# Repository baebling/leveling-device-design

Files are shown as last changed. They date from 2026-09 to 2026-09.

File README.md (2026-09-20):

# 수평유지 상부모듈 — 수동 턴버클 Rev M2 우선

> **2026-09-08 현행 범위:** [상부 패널 없는 공개형 프로파일 시연](requirements/current_open_frame_demo_scope_2026-09-08.md). 카트·적재물·사람, 별도 과조절 스토퍼/전용 받침, 전용 시험대 고정품은 구매하지 않는다. 남은 구매 전 작업은 활성20행 재검산과 최종 견적이다.

> **진행상황 기록:** [2026-09-07 M2R2-S220 현재 상태](logs/current_progress_2026-09-07.md)

> **현행 실행 우선순위:** [2026-09-07 수동 M2R2-S220 1순위 및 구매 전 게이트](requirements/current_variant_priority_2026-09-07.md). 전동 Rev E는 향후 참고안이며 현재 주문 기준이 아니다.

> **현행 시연 범위:** 카트·적재물 없는 자중 전용 감독하 시연. [구매 전 점검 결과와 열린 항목](verification/m2r2s220_no_cart_pre_purchase_audit_2026-09-07.md)

> **이전 한 축 상세 M2R2F2는 조립 방법 참고용 이력이다.** [3D 조립/분해 STEP과 렌더](outputs/manual_m2r2f2_one_axis/README.md), [확인 치수와 남은 가정](design_basis/manual_m2r2f2_one_axis_assembly_2026-09-05.md). 해당 모델의 MCL-12-F 칼라는 현행 M2R2-S220에서 SCSJ12-6으로 대체됐다.

> **현재 최신은 개념 승인 후 만든 M2R2-S220 장바구니 부품 CAD다.** [CAD 패키지 설명](outputs/manual_turnbuckle_rev_m2r2s220/README.md), [설계·자유도 검토](design_basis/manual_m2r2_cart_dof_assessment_2026-09-06.md). 하부 관절만 기존 4080 슬롯 안쪽으로 옮겨 중립 높이299.2 mm와 ±3° 길이 여유5.42 mm를 확보했다. 부품 간섭과 M5/M8 공구축 및 STEP 재읽기는 통과했지만, 독립 기계식 스톱·실제 카트 래치·STB 압축 정격 때문에 구매/제작 릴리스는 아직 아니다.

> **최신 검토 CAD는 M2R2 기성 연결부형이다.** 후속 요청에 따라 프로파일 길이 절단만 허용하고 맞춤 평판·부시·추가 구멍 가공을 없애는 조립안으로 변경했다. [최신 CAD 안내](outputs/manual_turnbuckle_rev_m2r2/README.md), [부품 후보·절단표·조립 순서](design_basis/manual_revm2r2_stock_connections_2026-09-05.md). 앞1/뒤2 직교 3-RPS, 검토 외곽700×700×344 mm. 아래 M2R1 및 120° 유지 방침은 이전 이력이다. 구매·제작·실물 하중 검증은 완료되지 않았다.

> **현재 CAD: Rev M2R1 (2026-09-05).** 사용자 CAD 진행 요청에 따라 기존 Rev M2 상부 연결부를 수정했다. [CAD 패키지 안내](outputs/manual_turnbuckle_rev_m2r1/README.md), [중립 STEP](outputs/manual_turnbuckle_rev_m2r1/step/M2R1_NEUTRAL_REVIEW.step), [전체 ZIP](output/Manual_3RPS_RevM2R1_CAD_Review_2026-09-05.zip). 112개 구성요소, 9자세 부품 간 간섭 0건, 5개 STEP 재수입 통과. 부시/구면 형상/핀 적층은 공칭 가정이며 제작·구매 미승인이다.

- **외관·조립 개선:** [표준 표면과 축 표시, 동일 링크 키트 3개](design_basis/manual_revm2_appearance_assembly_2026-09-05.md). 형상 재설계 대신 조립 표준화와 구조 가시성을 개선하는 개념이며 제작 승인 전이다.

> **2026-09-05 최종 사용자 결정:** 설명력과 기존 검증자료 활용을 고려해 턴버클형 Rev M2를 다시 1순위로 정했다. 경첩형 M3는 비교안으로 보관한다. 구조를 새로 단순화하기보다 좌나사품·상부 부시/핀·압축 사용 확인과 조달 묶음에 집중한다. 아래 같은 날짜의 M3 우선 결정은 대체된 이력이다.

- [최신 우선순위](requirements/current_turnbuckle_priority_2026-09-05.md)
- [최소 완성 방안 및 기존 검증 재감사](design_basis/manual_revm2_minimal_completion_2026-09-05.md)
- [조달 묶음](procurement/manual_revm2_procurement_groups_2026-09-05.md) / [공급처·담당자 문의 초안](procurement/manual_revm2_supplier_inquiry_drafts_2026-09-05.md)
- 기존 상부 부시의 실제 형상/공차는 검증되지 않았다. 구매·제작 미승인, 문의 미발송.

## 아래는 같은 날 앞서 검토한 M3 이력

> **2026-09-05 최신 결정:** 빠른 마무리·낮은 작업부담·재료 중심 조달을 위해 기계식을 1순위로 변경했다. 기존 구조를 유지할 의무는 없다. 새 우선 개념은 직교 경첩 2축과 조절나사 2개의 수동 수평조절·고정 구조다. 독립 상승/자동보정은 이번 실행 가정에서 제외한다. Rev E와 Rev M2는 보관안이며 아래의 이전 우선순위/BOM은 현재 주문 기준이 아니다.

- 최신 범위: [수동 우선순위](requirements/current_manual_priority_2026-09-05.md)
- 새 구조·예비계산·미해결사항: [M3 개념설계](concepts/manual_crossed_hinge_m3_2026-09-05.md)
- 상판 중심은 기울기에 따라 종속 이동한다. 절대 X/Y 고정이 필수이면 이 개념을 다시 검토한다.
- 현재 개념검토 단계이며 상세 CAD·구매·제작·실물검증은 미완료/미승인이다. 비용분류 및 축소 성과 인정도 확인 전이다.

## 아래는 2026-09-04 이전 전동식/수동식 작업 이력

> **2026-09-04 최신 상태:** Rev E의 제작도·전장함 배치·회로/배선·Mega2560 펌웨어·후보 BOM·시험절차를 release candidate로 구현했다. 27자세 OpenCascade 3회, 기존 Fusion 간섭 3회/단면 3회, Mega2560 실제 컴파일, 전체 226개 회귀시험과 RC1 전용시험 10개가 통과했다. 공급자/실물 검증이 남아 구매·제작·통전 승인은 아직 false다.

최신 자료:

- 실행 기준: [`requirements/current_variant_priority_2026-09-04.md`](requirements/current_variant_priority_2026-09-04.md)
- 디지털 감사: [`verification/RevE_PoC_release_candidate_audit_2026-09-04.md`](verification/RevE_PoC_release_candidate_audit_2026-09-04.md)
- 제작자료: [`fabrication/profile_radial_revE_release_candidate_2026-09-04`](fabrication/profile_radial_revE_release_candidate_2026-09-04)
- 전장·공급자·후보 BOM: [`outputs/profile_radial_revE_poc_release_candidate`](outputs/profile_radial_revE_poc_release_candidate)
- 타 PC 전달 ZIP: [`output/Profile_Radial_3RPS_RevE_PoC_RC1_2026-09-04.zip`](output/Profile_Radial_3RPS_RevE_PoC_RC1_2026-09-04.zip)
- 펌웨어: [`firmware/reve_leveling_controller`](firmware/reve_leveling_controller)
- 시험절차: [`verification/RevE_PoC_test_protocol_2026-09-04.md`](verification/RevE_PoC_test_protocol_2026-09-04.md)
- 수행 및 시행착오: [`logs/reve_poc_implementation_2026-09-04.md`](logs/reve_poc_implementation_2026-09-04.md)

> **2026-09-02 최신 상태:** `LM4075OE-1075 x3 + MDD10A x2 + Mega2560 + MPU6050` 전동 자동수평 Rev E의 CAD 단계를 완료했다. 실제 액추에이터 STEP를 넣은 Fusion 단일 조립체, 27자세 해석, OpenCascade 검사와 Fusion 간섭검사 3회가 통과했다. 수동 턴버클 Rev M2는 우선순위 2 백업안이며 두 안 모두 주문·제작 승인은 아직 false다.

```text
PRIORITY_1 = POWERED_PROFILE_RADIAL_3RPS_REVE_ACTUAL_VENDOR
PRIORITY_2 = MANUAL_TURNBUCKLE_3RPS_REV_M2_BACKUP
TARGET_POWERED_Z = 0-50 mm
TARGET_PITCH_ROLL = +/-3 deg
CAD_STAGE = COMPLETE
PURCHASE_RELEASE = FALSE
FABRICATION_RELEASE = FALSE
COMMISSIONING_RELEASE = FALSE
```

우선순위 1에서 먼저 읽을 파일:

- 최신 우선순위: [`requirements/current_variant_priority_2026-09-02.md`](requirements/current_variant_priority_2026-09-02.md)
- 전동 제어 기준: [`design_basis/priority1_powered_control_architecture_2026-09-02.md`](design_basis/priority1_powered_control_architecture_2026-09-02.md)
- Rev E CAD·반복검증: [`design_basis/Profile_Radial_3RPS_RevE_CAD_validation_2026-09-02.md`](design_basis/Profile_Radial_3RPS_RevE_CAD_validation_2026-09-02.md)
- 60행 국내 구매형 BOM: [`procurement/profile_radial_reve_domestic_master_bom_2026-09-02.csv`](procurement/profile_radial_reve_domestic_master_bom_2026-09-02.csv), [`설명서`](procurement/profile_radial_reve_domestic_master_bom_2026-09-02.md)
- 검토용 Excel BOM: [`outputs/profile_radial_revE_actual_vendor/Profile_Radial_3RPS_RevE_Domestic_BOM_2026-09-02.xlsx`](outputs/profile_radial_revE_actual_vendor/Profile_Radial_3RPS_RevE_Domestic_BOM_2026-09-02.xlsx)
- Fusion 단일 조립체: [`outputs/profile_radial_revE_actual_vendor/Profile_Radial_3RPS_RevE_ACTUAL_VENDOR.f3d`](outputs/profile_radial_revE_actual_vendor/Profile_Radial_3RPS_RevE_ACTUAL_VENDOR.f3d)
- STEP·렌더·검증 패키지: [`outputs/profile_radial_revE_actual_vendor`](outputs/profile_radial_revE_actual_vendor)
- 국내 제어부 조사: [`web_research/domestic_electronics_research_log_2026-09-02.md`](web_research/domestic_electronics_research_log_2026-09-02.md)
- 타 PC 전달 패키지: [`output/Profile_Radial_3RPS_RevE_CAD_Package_2026-09-02.zip`](output/Profile_Radial_3RPS_RevE_CAD_Package_2026-09-02.zip), [`SHA-256`](output/Profile_Radial_3RPS_RevE_CAD_Package_2026-09-02.zip.sha256)

우선순위 2 수동 백업안:

- 설계 기준: [`design_basis/manual_turnbuckle_rev_m2_2026-09-02.md`](design_basis/manual_turnbuckle_rev_m2_2026-09-02.md)
- BOM: [`procurement/manual_turnbuckle_rev_m2_bom_2026-09-02.md`](procurement/manual_turnbuckle_rev_m2_bom_2026-09-02.md)
- CAD/검증 결과: [`outputs/manual_turnbuckle_rev_m2`](outputs/manual_turnbuckle_rev_m2)
- 자립성 감사: [`outputs/manual_turnbuckle_rev_m2/Manual_3RPS_RevM2_self_standing_verification.json`](outputs/manual_turnbuckle_rev_m2/Manual_3RPS_RevM2_self_standing_verification.json)
- 최신 타 PC 전달 패키지: [`output/Manual_3RPS_RevM2_CadQuery_Package_v2_2026-09-02.zip`](output/Manual_3RPS_RevM2_CadQuery_Package_v2_2026-09-02.zip)
- 재생성: `powershell -ExecutionPolicy Bypass -File scripts/run_manual_turnbuckle_rev_m2.ps1`

> **2026-09-01 과거 결정:** 전동 액추에이터·IMU·모터제어·전원장치를 제외하고 수동식으로 전환했으나, 이 결정은 2026-09-02의 우선순위 변경으로 대체됐다. 아래 내용은 수동 백업안의 이력이다.

현재 상태:

```text
BACKUP_VARIANT = MANUAL_ADJUSTABLE_3RPS_HISTORY
POWERED_VARIANT = PRIORITY_1_REACTIVATED
TARGET_MANUAL_Z = 0-50 mm provisional
TARGET_PITCH_ROLL = +/-3 deg
PURCHASE_RELEASE = FALSE
FABRICATION_RELEASE = FALSE
```

현재 먼저 읽을 파일:

- 수동 요구사항: [`requirements/current_manual_scope_2026-09-01.md`](requirements/current_manual_scope_2026-09-01.md)
- 수동 설계 기준: [`design_basis/manual_adjustable_3rps_baseline_2026-09-01.md`](design_basis/manual_adjustable_3rps_baseline_2026-09-01.md)
- 전동안 보관 기록: [`design_basis/archived_powered_control_architecture_2026-09-01.md`](design_basis/archived_powered_control_architecture_2026-09-01.md)
- BOM 변경표: [`procurement/manual_3rps_bom_delta_2026-09-01.csv`](procurement/manual_3rps_bom_delta_2026-09-01.csv)
- 인수인계: [`PROJECT_HANDOFF.md`](PROJECT_HANDOFF.md)

수동안은 기존 Rev D의 700 x 700 mm 프로파일 프레임, 250 mm 지지 반경과 90/210/330 deg 지지점은 재사용 후보로 유지한다. 27자세 이상모델의 요구 핀 중심 길이는 212.137-297.864 mm이며, 새 수동 지지대의 예비 설계 포락체는 205-305 mm다. 정확한 스크루·너트·조인트·잠금장치를 선정하고 Fusion 조립체를 다시 검사하기 전에는 주문하거나 제작하지 않는다.

## 보관된 전동안 - 프로파일 방사형 3-RPS Rev D

> **보관 시점 최종 갱신:** Rev D 기술 BOM을 62개 고유 행으로 평탄화했다. 가격 확인분은 VAT 포함 화면가 1,589,208원이고, 이 중 나비엠알오 45행 소계는 1,085,370원이다. 별도 견적이 필요한 A6061 가공품은 9행이며 Fusion 조립체는 루트 전체 간섭 0건과 회귀검사 18개를 유지한다.

> **전동안 보관 판정:** 아래 기술 BOM은 현재 `ARCHIVED_DO_NOT_ORDER`다. 당시에도 액추에이터 정확 옵션/배선자료, LMB-10 핀 포함품, 가공 견적과 최종 결제총액이 닫히지 않아 `purchase_release=false`, `fabrication_release=false`였다.

전동안 보관 파일:

- Fusion 원본: [`outputs/profile_radial_revD_fusion_native/Profile_Radial_3RPS_RevD_NATIVE.f3d`](outputs/profile_radial_revD_fusion_native/Profile_Radial_3RPS_RevD_NATIVE.f3d)
- 최종 통합 BOM: [`outputs/bom/Profile_Radial_3RPS_RevD_Final_BOM_2026-09-01.xlsx`](outputs/bom/Profile_Radial_3RPS_RevD_Final_BOM_2026-09-01.xlsx), [`CSV`](procurement/profile_radial_revd_final_master_bom_2026-09-01.csv), [`설명서`](procurement/profile_radial_revd_final_master_bom_2026-09-01.md)
- Rev D 설계·조립 기준: [`design_basis/profile_radial_revD_fusion_native_2026-08-31.md`](design_basis/profile_radial_revD_fusion_native_2026-08-31.md)
- Rev D 구조·체결 BOM: [`procurement/profile_radial_revD_structural_bom_2026-08-31.md`](procurement/profile_radial_revD_structural_bom_2026-08-31.md)
- Rev D 최신 분할 구매안: [`procurement/profile_radial_revd_split_source_purchase_plan_2026-09-01.md`](procurement/profile_radial_revd_split_source_purchase_plan_2026-09-01.md), [`주문 그룹 CSV`](procurement/profile_radial_revd_split_source_order_groups_2026-09-01.csv)
- Rev D 발주표 재감사: [`procurement/profile_radial_revd_order_readiness_audit_2026-09-01.md`](procurement/profile_radial_revd_order_readiness_audit_2026-09-01.md)
- Rev D 나비엠알오 실상품 후보 BOM: [`procurement/profile_radial_revd_navimro_candidate_bom_2026-09-01.md`](procurement/profile_radial_revd_navimro_candidate_bom_2026-09-01.md), [`CSV`](procurement/profile_radial_revd_navimro_candidate_bom_2026-09-01.csv)
- 과거 일괄 발주 준비도: [`procurement/profile_radial_revd_single_order_readiness_2026-09-01.md`](procurement/profile_radial_revd_single_order_readiness_2026-09-01.md)
- ISO 검토 이미지: [`outputs/profile_radial_revD_fusion_native/Profile_Radial_3RPS_RevD_Fusion.png`](outputs/profile_radial_revD_fusion_native/Profile_Radial_3RPS_RevD_Fusion.png)
- 가공 DXF/좌표표: [`outputs/profile_radial_revD_fusion_native/fabrication`](outputs/profile_radial_revD_fusion_native/fabrication)
- 기존 Rev C와 그 이전 자료는 비교·시행착오 기록이며 현재 주문 기준이 아니다.

> **2026-08-31 이전 상태(Rev C):** Rev B 기각 후 실제 120 deg 방사형 3-RPS를 복구했던 단계다. 수동 전환 직전 전동안에서는 이 구조의 중앙 허브판까지 제거한 Rev D가 마지막 기준이었다.

이 저장소는 기존 자재운반 카트와 하부 이동체 사이에 설치하는 독립형 수평유지·리프팅 상부모듈 및 기계식 카트 결합 인터페이스의 PoC 개념설계 자료이다.

## 2026-09-01 보관된 전동안의 마지막 방향

수동 전환 직전까지 과거 중앙 카단, 잘못 조립된 Rev B, 중앙 허브판을 사용한 Rev C는 **역사/비교 자료**로 보관했고, 전동안의 마지막 기준은 허브판 없는 프로파일 방사형 Rev D였다.

- 목표 구조: 하부 회전힌지(R) + 엔코더 액추에이터(P) + 상부 구면 로드엔드(S) × 3
- 허용 자유도: Z, pitch, roll
- 기구 구속: 세 하부 R축 평면 구속으로 X, Y, yaw가 종속되며, 27자세 해석에서 최대 보정량은 X 0.342 mm, Y 0.171 mm, yaw 0.079 deg다.
- 현재 Fusion 360 검토 패키지: [`output/Profile_Radial_3RPS_RevD_Fusion360_Native.zip`](output/Profile_Radial_3RPS_RevD_Fusion360_Native.zip)
- Rev D 설계 기준: [`design_basis/profile_radial_revD_fusion_native_2026-08-31.md`](design_basis/profile_radial_revD_fusion_native_2026-08-31.md)
- Rev D 구조 BOM: [`procurement/profile_radial_revD_structural_bom_2026-08-31.md`](procurement/profile_radial_revD_structural_bom_2026-08-31.md)
- 로컬 어댑터·스톱 가공자료: [`outputs/profile_radial_revD_fusion_native/fabrication`](outputs/profile_radial_revD_fusion_native/fabrication)
- Rev B 기각 재감사: [`design_basis/revB_assembly_reaudit_2026-08-31.md`](design_basis/revB_assembly_reaudit_2026-08-31.md)
- 유지 검토 후보: LM4075OE-1075 24 V/100 mm/5 V encoder, DMD-150 ×3, Arduino Mega 2560, WT901C
- 목표 운동: Z 0~50 mm, pitch/roll 각각 ±3°; Rev D 요구 핀 길이 218.958~279.846 mm
- Rev D 포락체: 접힘 상태 700×700×300 mm, Fusion 네이티브 컴포넌트 138개
- Rev D 절단표: 하부 4040 700×2/620×4, 상부 3030 700×2/640×4
- 디지털 검증: 방위각 90/210/330 deg, PHS 최대 굴절 4.096 deg, STEP 289 solids, Fusion 전체 간섭 0건, 독립 감사 교차 0 mm3
- 제작 게이트: LM4075OE 아이 폭·공급 STEP, LMB 핀/리테이너, 상부 심·숄더볼트, 스톱 정확 SKU, A1 어댑터+스톱 1차품과 한 축 실조립

아래의 과거 Phase 2, 중앙 카단, Firgelli/DIHOOL, NAVIMRO Rev D/E와 프로파일 Rev A/B/C 자료는 최신 구매지시가 아니다. Rev D의 노란 LM4075OE 외피, 파란 로컬 어댑터와 빨간 스톱도 공급자 자료·실물시험 전까지 제작 승인값은 아니다.

2026-08-24부터 기존 예비 CAD를 Phase 0 웹 조사 기반 파라미터 선정 단계로 되돌려 외부 피드백과 사용자 요구를 다시 반영했다. 2026-08-25에는 **10 kg 가반하중, 약 10 kg 빈 카트, 연결 전 장치 높이 250~300 mm, Pitch/Roll ±3°, 쉬운 가공·제작·조립 우선, 알루미늄 프로파일 카트 리시버**를 기준으로 확정했고, 2026-08-26 사용자가 정확히 **`APPROVE CONCEPT`**를 입력해 Phase 2 상세 CAD 진행을 승인했다. 이후 첫 중앙 짐벌/스톱 카트리지안이 지나치게 복잡하다는 사용자 피드백을 받아 당시 CAD를 세 액추에이터가 120° 방사형 주 구조를 이루는 `RADIAL_3_CLEAN`으로 바꿨다. 2026-08-27에는 움직이지 않는 감독하 저속 시험대 조건에 맞춰 외부 D4N/캠 패키지를 보관안으로 내리고 `LS-01M_STATIC_BENCH_MINIMAL`과 공장 아이 중심의 `JNT-CG-01` 목업 시드를 추가했다.

> 모든 Phase 2 산출물은 `PRELIMINARY — NOT APPROVED FOR FABRICATION` 상태이며 사람 운송용이 아니다.

## 이어받기 문서

다른 컴퓨터에서 이어서 작업할 때는 먼저 아래 파일을 읽는다.

- `PROJECT_HANDOFF.md`: 현재 상태, Phase 게이트, 기존 진행 흐름, 시행착오, 다음 작업
- `design_basis/minimal_radial_revC_2026-08-31.md`: 현재 120 deg 방사형 구조, 운동학, 체결축, 검증과 남은 불확실성
- `outputs/minimal_radial_revC/FUSION360_IMPORT_AND_ASSEMBLY_GUIDE.md`: Rev C Fusion 360 파일 선택과 실제 조립 순서
- `procurement/minimal_radial_revC_structural_bom_2026-08-31.md`: 현재 프로파일·허브판·브래킷·체결품 수량과 발주 게이트
- `design_basis/phase2_cad_baseline_2026-08-26.md`: 첫 상세 CAD의 보관 기록; 대형 중앙안은 현재 비선호
- `design_basis/radial_3_clean_baseline_2026-08-26.md`: 사용자 디자인 피드백 후 채택한 활성 방사형 3액추에이터 기준
- `outputs/reports/phase2_cad_update_summary.md`: 이번 CAD 갱신 결과 요약
- `outputs/reports/phase2_review_render_pack.md`: 상판 제거 내부도, 정·측·평면도, 분해도 및 번호 조립도 안내
- `design_basis/static_bench_minimal_variant_2026-08-27.md`: 정지형 저속 시험대 최소 구성과 삭제/유지 범위
- `design_basis/actuator_limit_package_cad_2026-08-27.md`: LS-01M 쌍봉식 기계 스톱 상세 CAD 기준
- `design_basis/factory_clevis_gimbal_seed_2026-08-27.md`: JNT-CG-01 공장 아이 중첩 짐벌 목업 시드
- `outputs/phase2/actuator_limit_package_summary.md`: LS-01 위치·정적 스크리닝·미해결 검증 요약
- `design_basis/user_confirmed_scope_2026-08-25.md`: 10 kg 적재/10 kg 카트/250~300 mm/±3°/쉬운 제작 우선 사용자 확인 기준
- `design_basis/cart_profile_receiver_concept_2026-08-25.md`: 알루미늄 프로파일 기반 카트 리시버 예비 개념
- `design_basis/cart_profile_receiver_layout_screen.md`: CR-01 알루미늄 프로파일 리시버 배치/질량/하중 스크리닝
- `design_basis/cart_receiver_hardpoint_screen.md`: CR-01-H1 locator/rest pad/latch keeper 하드포인트 스크리닝
- `design_basis/cart_receiver_connector_topology_screen.md`: CR-01-H2 슬롯너트/백킹플레이트/포지티브 스토퍼 토폴로지 스크리닝
- `design_basis/cart_receiver_connector_detail_screen.md`: CR-01-H3 하드포인트별 연결 스택/서비스 접근성 스크리닝
- `design_basis/cart_receiver_hardware_selection_screen.md`: CR-01-H4 조립·목업용 하드웨어 시드 스크리닝
- `outputs/reports/phase0_summary.md`: Phase 0 웹 조사 기반 파라미터 선정 요약
- `outputs/reports/final_candidate_parameter_pack.md`: 승인된 개념과 남은 증거를 정리한 파라미터 팩 v1.2
- `outputs/reports/cart_profile_receiver_summary.md`: 카트 리시버 CR-01 요약
- `outputs/reports/cart_receiver_hardpoint_summary.md`: 카트 리시버 CR-01-H1 하드포인트 요약
- `outputs/reports/cart_receiver_connector_summary.md`: 카트 리시버 CR-01-H2 연결/스토퍼 요약
- `outputs/reports/cart_receiver_connector_detail_summary.md`: 카트 리시버 CR-01-H3 연결 스택/접근성 요약
- `outputs/reports/cart_receiver_hardware_selection_summary.md`: 카트 리시버 CR-01-H4 하드웨어 시드 요약
- `design_basis/design_basis_report.md`: 설계 변수 선정 근거 보고서
- `design_basis/guide_mobility_review.md`: 중앙 가이드/조인트 자유도 검토
- `design_basis/joint_candidate_screen.md`: 액추에이터 조인트/중앙 카단 후보 스크리닝
- `design_basis/joint_detail_screen.md`: 조인트 브래킷 하중경로 및 중앙 yaw 토크 스크리닝
- `design_basis/actuator_bracket_package_screen.md`: JNT-BR-01 HRT8E형 이중전단 브래킷 시드 스크리닝
- `design_basis/actuator_joint_detail_cad_2026-08-27.md`: 공식 HRT8E 외형을 반영한 18 mm 요크/부싱/핀 유지장치 상세 CAD 기준
- `design_basis/central_yaw_path_comparison.md`: 중앙 yaw 토크 경로 후보 비교
- `design_basis/yaw_a_architecture_definition.md`: YAW-A 선호 구조의 후보 파라미터 정의
- `design_basis/yaw_a_gimbal_kinematic_definition.md`: YAW-A 두 축 요크의 축 순서, yaw 구속, 각도 스토퍼 정의
- `design_basis/combined_workspace_operating_window.md`: WS-01-H20 통합 작업영역/가이드 후보
- `design_basis/travel_limit_and_stop_strategy.md`: 전기 리미트와 기계식 스토퍼의 분리 전략
- `design_basis/pre_cad_verification_plan.md`: CAD 전 물리 목업/측정 통과 기준
- `outputs/reports/guide_mobility_summary.md`: 중앙 가이드 모빌리티 분석 요약
- `outputs/reports/joint_candidate_summary.md`: 조인트 후보 스크리닝 요약
- `outputs/reports/joint_detail_summary.md`: 조인트 상세 스크리닝 요약
- `outputs/reports/actuator_bracket_package_summary.md`: JNT-BR-01 액추에이터 브래킷 요약
- `outputs/reports/central_yaw_path_summary.md`: 중앙 yaw 경로 비교 요약
- `outputs/reports/yaw_a_architecture_summary.md`: YAW-A 후보 파라미터 요약
- `outputs/reports/yaw_a_gimbal_kinematic_summary.md`: YAW-A 축 순서/스토퍼 요약
- `outputs/reports/combined_workspace_operating_window_summary.md`: WS-01-H20 작업영역 요약
- `outputs/reports/travel_limit_and_stop_summary.md`: 리미트/스토퍼 요약
- `web_research/joint_sources.md`: 조인트/카단 후보 출처 메모
- `logs/feedback_recheck_2026-08-24.md`: 외부 피드백 반영 및 재점검 기록
- `logs/work_history.md`: 작업 이력과 시행착오 로그
- `logs/environment_setup.md`: 이 PC에서 수행한 환경 설정 기록

현재 승인 상태:

```text
APPROVE CONCEPT RECEIVED 2026-08-26
REV B REJECTED AFTER ASSEMBLY AXIS REAUDIT
REV C TRUE 120-DEG RADIAL DIGITAL CORE CHECKS PASSED
DIGITAL_CORE_ASSEMBLY_PASS_EYE_WIDTH_AND_STOP_MOUNT_OPEN
FABRICATION_RELEASE FALSE
PURCHASE_RELEASE FALSE
NOT APPROVED FOR FABRICATION
```

상세 CAD 진행은 승인됐지만 제작 릴리스는 승인되지 않았다. 첫 제작은 실측값을 반영한 조인트 1개와 액추에이터 카세트 1개 목업으로 제한한다. 무간섭·기계 스톱·질량·전원 기능을 확인하기 전에는 나머지 5개 조인트와 2개 카세트를 복제하지 않는다.

## 권장 개념

- 중심 반경 91 mm에서 상부 반경 400 mm로 펼쳐지는 3점 방사형 사선 액추에이터 개념
- 세 사선 액추에이터는 120° 방사형으로 동일 배치하며 승강과 Pitch/Roll을 직접 만든다.
- 중앙 키드 텔레스코픽 슬라이드 + 컴팩트 카단은 X/Y/Yaw 구속만 담당하며, 상판 중앙 개구나 대형 브리지를 사용하지 않는다.
- 직렬 HRT8E 어댑터는 양단 길이 증가 때문에 현재 319 mm 수축 길이를 만족하지 못해 활성안에서 제외하고 보관 후보로 둔다.
- 활성 조인트 시드는 `JNT-CG-01`: 액추에이터 공장 M8 핀을 한 축으로 쓰고, 내부 크래들의 대향 M8 트러니언으로 직교축을 만드는 영점 오프셋 중첩 짐벌이다.
- JNT-BR-01 상세 시드: 공식 HRT8E 8/23/11 mm 외형, 5.29 kN 축방향 정적값, ball center를 지나는 8 mm 이중전단 핀/러그, 18 mm 지지간격, 교체형 부싱과 핀 유지장치 포락체; 실제 14° 무간섭 목업 통과가 유지 조건
- 조인트 브래킷은 하중선을 볼 중심에 맞춰야 하며, 나사부 외팔보 지지는 현재 스크리닝에서 설계 차단점
- 작은 카탈로그 U-joint는 여전히 주 yaw 구속 경로로 쓰기보다 YAW-A keyed guide 구조 안에서 보조/형상 참고로만 검토
- 중앙 yaw 토크 경로의 원리는 유지하되, 활성 형상은 120 mm 이내 컴팩트 카단으로 축소하고 세 액추에이터를 설계의 주 구조로 둔다.
- YAW-A 후보값: 8° 설계 포락선, 10° 총 기울기 포락선, 하부 +Y pitch/상부 local +X roll 축 순서, 각 축 +/-7° 물리 스토퍼, yaw clearance 0.2 mm target/0.3 mm max
- WS-01-H20 후보: 270 mm 접힘, 100 mm 리프트, 195/220 mm guide, +/-3° 전 구간에서 11.13 mm 이상 actuator soft reserve 및 88 mm 이상 guide overlap
- 승인된 개념과 남은 검증 항목은 최종 후보 파라미터 팩 v1.2 `outputs/reports/final_candidate_parameter_pack.md`에 정리됨
- 허용 자유도: Z, Pitch, Roll
- 구속 자유도: X, Y, Yaw
- 사용자 확인 1차 PoC 목표: 적재물 10 kg, 빈 카트 약 10 kg, 연결 전 장치 높이 250~300 mm, Pitch/Roll 각각 ±3°, 쉬운 제작/조립 우선
- 목표 리프트: WS-01-H20 기준 100 mm와 ±3° 조합은 계산상 통과했지만, 실제 actuator/guide/stop 목업 증거 전에는 보장으로 주장하지 않음
- 상부 하이브리드 구조 후보: HFS8-4040 알루미늄 프레임 + 15 mm 주조 아크릴 상판 + 금속 하중분산판
- 카트 리시버 방향: CR-01 2-레일 알루미늄 프로파일 키트 + CR-01-H1 위치결정핀/받침/래치용 국부 금속 하드포인트 + CR-01-H2 슬롯 체결/포지티브 스토퍼 토폴로지
- CR-01-H2 선호안: 슬롯너트와 M8급 체결은 mock-up 조정/클램프용으로 쓰고, 최종 반복 위치와 X/Y/Yaw 전단은 숄더/키/도웰/포지티브 스토퍼가 담당
- CR-01-H3 스택 규칙: master locator는 X/Y 고정, secondary locator는 Y만 잡고 X는 풀기, rest pad는 Z seating만, latch keeper는 preload/uplift만 담당
- CR-01-H4 하드웨어 시드: master는 12 mm removable round bushing + replaceable stop, secondary는 X-slot/diamond Y-only locator, rest pad는 40 x 30 mm shim seat, latch keeper는 별도 기계식 secondary lock을 유지
- 카트 결합 원칙: 원뿔형 기계식 위치결정핀 + 래치, 단 래치 형번/수량/예압은 미확정
- 시험대 최소 보호: Firgelli 내장 비조정식 종단 리미트와 별개의 LS-01M 기계식 칼라를 유지한다. 외부 D4N, 전기 캠, 슬롯 브래킷과 전용 산업용 비상정지품은 활성 CAD/BOM에서 제외했다.
- LS-01M datum: 공식 Firgelli MB21 STEP 포락체를 220 mm 고정 station에 적용하고 이동 datum은 전방 clevis pin centre다. 12 x 320 mm twin rod와 104/298 mm 기계 칼라 offset을 사용하며 chrome rod clamp는 폐기했다.
- Firgelli 원본 STEP 4종(actuator/MB21/MB20/MB17), 분리 진단 렌더 2종과 SHA-256 기록은 `references/vendor/firgelli/` 및 `design_basis/firgelli_mount_datum_review_2026-08-27.md`에 보존
- 현재 핵심 open item은 선택한 450 lbf/8-inch 액추에이터의 실제 아이 두께, 공급 핀 스택과 MB21 외부 스톱 하중 허용 여부다. `JNT-CG-01`은 이 실측값을 넣은 1개 목업을 통과하기 전에는 6개분 제작치로 동결하지 않는다.

## Phase 2 주요 산출물

- `outputs/phase2/phase2_engineering_report.md`: 운동학, 하중, 민감도, 위험
- `outputs/phase2/diagonal_design_decision.md`: 사선 배치 대안 비교와 선정 근거
- `outputs/phase2/acrylic_feasibility.md`: 전체 아크릴/하이브리드 비교
- `outputs/phase2/purchase_research.md`: 공식 판매처 기반 부품 조사
- `outputs/phase2/phase2_bom.csv`: 구매·가공 BOM과 확인 가격
- `outputs/phase2/actuator_limit_package_summary.md`: LS-01 스톱·리미트 계산/선정 요약
- `outputs/cad/step/`: 7개 동작상태 조립 STEP + 2개 중앙 가이드/짐벌 상세 STEP + 방사형 액추에이터 조인트 및 LS-01 상세 STEP
- `outputs/cad/glb/`: 중립상태 GLB
- `outputs/cad/stl/`: IMU 브래킷·케이블 가이드
- `outputs/cad/dxf/`: 하부판·아크릴 상판 예비 2D 프로파일
- `outputs/renders/`: Phase 2 상태/중앙/방사형/조인트/LS-01M/JNT-CG-01 상세, 도면성 검토 및 vendor STEP 진단 렌더
- `outputs/phase2/artifact_manifest.json`: 산출물 크기와 SHA-256

## 재생성 및 검증

Windows PowerShell에서 `scripts/run_phase2.ps1`을 실행하면 계산 보고서, CAD, 렌더, 체크섬을 재생성하고 테스트를 수행한다. CadQuery 런타임은 `vendor/python`에 포함되어 있다.

```powershell
& .\scripts\run_phase2.ps1
```

2026-08-27 최신 검증: 단위 테스트 109개 통과, CAD 산출물 17개, pipeline 렌더 24개. 활성 BOM은 15행이며 HRT8E 구형 joint-package와 D4N/A22E 품목은 모두 0건, source ID 누락도 없다.

## 상태

`REV C TRUE 120-DEG RADIAL - DIGITAL CORE PASS - EYE WIDTH AND STOP MOUNT OPEN - NOT APPROVED FOR FABRICATION`

## NAVIMRO 단일 주문 패키지

2026-08-28 Rev D 기준으로 필요한 구매 자재와 부속을 나비엠알오 CSV 50개 감사행, 47개 활성 주문행으로 정리했다. 알려진 가격 합계는 VAT 포함 2,767,127원이며 팬/필터 로그인 가격, 착불비와 가공비는 제외된다.

- `procurement/navimro_single_order_bom.csv`: 주문용 원본 목록
- `procurement/navimro_single_order_bom.md`: 사람이 읽는 구매 요약
- `procurement/navimro_preorder_inquiry_2026-08-27.md`: 판매처 통합문의 문안
- `design_basis/navimro_single_order_redesign_basis_2026-08-27.md`: 나비엠알오 부품 기반 재설계 기준
- `design_basis/navimro_pin_lug_interface_assumption_2026-08-27.md`: 평판 미포함 M8-to-eye 핀/러그 인터페이스 가정과 발주 확인 게이트

액추에이터의 실제 M8 양단 형상과 핀 중심 길이, Hall/배선/전류, 래치/칼라 정격이 확인되기 전에는 반품불가 품목을 발주하지 않는다. active 상세 CAD는 DIHOOL A2 보수 포락체와 JFT-8R 카탈로그 형상을 사용한다.

단일 주문 패키지 추가 후 전체 단위 테스트 110개와 BOM 소계/CSV 무결성 검사가 통과했다.

웹 도면 재검토 후 평판 미포함 M8-to-eye 핀/러그 구성을 계획 기준으로 선택하고 수직 관절간격을 185 mm로 복원했다. `K92931811`의 실제 축단 부속, 핀 중심 길이와 Hall/배선 옵션은 판매처 확인이 남아 있다.

최신 결정: 공식 도면상 U/H 브래킷은 서로 쌓는 2축 세트가 아니라 단일축 장착 대안이므로 주문 수량을 0으로 내렸다. 대신 `K02020097 / JFT-8R` 구면 로드엔드 6개와 `NVR-P03/P04/P16` 이중 전단 용접 요크를 사용한다. 접힘 모듈 높이는 300 mm, 전 작동영역 핀 중심 길이는 269.040~394.209 mm, 여유 포함 최대 관절각은 10.852°다. 실제 A2 M8 양단 형상, 핀 중심 Lmin/Lmax, Hall/배선/전류와 STEP 확인은 발주 전 필수다.

2026-08-28 DIHOOL `DHLA6000-A2 24V` 공식 페이지에서 A2가 `평판 + M8 나사 설치형`이고 중앙 튜브 장착 헤드가 탈착식이라는 설명을 확인했다. 다만 현재 BOM의 `K92931811 / LA2000-125150`과 동일 모델이라는 증거는 없으며, 표시된 A2 STEP 링크도 403으로 내려받지 못했다. 따라서 Rev D의 M8 어댑터는 계속 provisional로 두고 판매처에 정확한 납품 모델·포함품·STEP를 요청한다.

사용자가 2026-08-28 나비엠알오 납품 사양을 `DC 12 V / 2000 N / 150 mm stroke / 5 mm/s`로 확인했다. 이 네 항목과 12 V 버스는 Rev D 확정 입력으로 승격했고, DHLA6000의 24 V·6000 N·72 W 값은 적용하지 않는다. A1/A2 설치형, M8 암/수와 물림 길이, pin-center Lmin/Lmax, Hall/배선/전류와 실제 STEP는 계속 발주 gate다.

추가 비교에서 DIHOOL `DHLA6000-A2` 12 V와 24 V 페이지가 동일 외형도와 동일 A2 STEP 이름을 공유함을 확인했다. 따라서 DHLA6000 제품군 안에서 전압형 간 기계 하드웨어 공용 가능성은 높다. 그러나 현재 주문품은 `LA2000-125150`, 2000 N/5 mm/s이고 DHLA6000 표는 2000 N을 15 mm/s와 짝지으므로 두 제품군의 기계부가 같다고 확대 해석하지 않는다.

전원·제어 구매품은 AC 입력, 12 V/29 A PSU, DMD-150 3채널, Mega2560 PRO, BNO055, 5 V DC-DC, AC/DC 차단기, 배선·단자·접지·함체·냉각까지 포함한다. 배터리/BMS/충전기는 정지 시험대라 제외했다. 제조사 매뉴얼로 DMD-150의 IN1/IN2/PWM, brake/coast 논리와 12 V 180 W, 무냉각 연속 12 A/냉각 시 15 A를 확인했다. 남은 전기 gate는 실제 액추에이터 Hall/배선/정격·기동·스톨전류, 회생전압용 양방향 TVS 선정·시험, 최종 배선도와 펌웨어다. 전기부는 계속 `하드웨어 대부분 포함, 최종 배선/통전 미승인` 상태이며 상세는 `procurement/electrical_control_completeness_2026-08-28.md`와 `design_basis/dmd150_official_manual_review_2026-08-28.md`를 따른다.

평판 미포함 핀/러그 관절의 독립 예비 STEP과 검토 렌더를 생성했으며, 전체 단위 테스트 112개가 통과했다.

## NAVIMRO 제작 CAD Rev A - 현재 기준

사용자의 400만원 상한과 제작 CAD/가공도면 요청을 반영해 기존 Firgelli CAD와 별도로 NAVIMRO 제작본을 완성했다. 이제 active NAVIMRO 산출물은 `outputs/navimro_fabrication/`과 `output/pdf/`에 있으며, 이전의 "active CAD는 아직 Firgelli" 문장은 역사 기록으로만 남는다.

- 조립 STEP 6상태: 접힘, 중립, 상승, 최대 pitch, 최대 roll, 최대 pitch+roll.
- 평철 DXF `NVR-P01`~`P14`, 900x800x15 아크릴 DXF, 4040/축/평철 절단표.
- moving Ø12 shafts + fixed LMF12UU 4개 + moving SK12 4개 중앙가이드.
- 50x50x6 6장 적층 Cardan cross와 네 M8 opposed trunnion.
- 접힘 전체 높이 300 mm, 전체 +/-3도와 Z 0/100 mm corner sweep 길이 273.196~385.349 mm.
- Rev A 당시 나비엠알오 49행 확정가 2,799,522원, 전체 계획 3,799,522원, 예산 여유 200,478원. 현재 Rev D 금액은 아래 최신 절을 따른다.
- 제작도면 PDF 11쪽과 조립·발주 PDF 11쪽은 전 페이지 렌더 검수 완료.
- 전체 단위 테스트 123개 통과.

핵심 문서:

- `design_basis/navimro_fabrication_release_revA_2026-08-27.md`
- `output/pdf/NAVIMRO_leveling_module_fabrication_drawings_revA.pdf`
- `output/pdf/NAVIMRO_leveling_module_assembly_and_order_pack_revA.pdf`
- `outputs/navimro_fabrication/artifact_manifest.json`

재생성:

```powershell
& .\scripts\run_navimro_fabrication.ps1
```

주문제작 액추에이터는 아직 즉시 결제하면 안 된다. 실제 pin-center 길이, 양단 M8 암/수 형상과 물림 길이, Hall/배선/전류/STEP, JFT-8R 적합성, CR-3001 및 collar 정격을 서면 확인한 뒤 transfer-drill 치수와 전원 정격을 최종 반영한다.

## 그림 중심 조립 매뉴얼 Rev B

2026-08-27 사용자 검토에서 기존 조립·발주 PDF의 조립 순서가 글 위주라 실제 연결 관계를 파악하기 어렵다는 문제가 확인되었다. 이를 보완해 `output/pdf/NAVIMRO_visual_assembly_manual_revB.pdf`를 추가했다.

- 전체 구조 분해도 1장과 하부에서 상부로 이어지는 8단계 누적 CAD 그림을 포함한다.
- 각 단계에서 새로 장착할 부품은 주황색, 이미 조립된 부품은 회색으로 표시한다.
- 각 단계마다 사용 부품, 조립 방법, 완료 판정을 같은 페이지에 배치한다.
- 중앙 가이드와 Cardan 관절은 확대 그림으로 별도 설명한다.
- 마지막 페이지는 현장에서 인쇄해 사용할 수 있는 한 장 조립 순서표다.
- CAD에 남아 있던 `DHLA2000_A1` 명칭은 확정 형식으로 오해되지 않도록 `LA2000 pin/lug planning envelope`로 변경했다.
- 조립 단계 그룹 검사 3개를 추가한 뒤 전체 단위 테스트 126개가 통과했다.

## Fusion 360 상세 CAD Rev C

사용자 요청에 따라 모든 프로파일, 철판, 접합판, 볼트, 와셔, T너트, nyloc 너트, pivot bolt, 상판 spacer가 보이는 상세 조립체를 추가했다.

- 전달 패키지: `output/NAVIMRO_Fusion360_detailed_CAD_revC.zip`
- Fusion 360 권장 파일: `outputs/navimro_fusion360_revC/step/NAVIMRO_detailed_neutral_revC.step`
- 분해 검토: `NAVIMRO_detailed_exploded_revC.step`
- 접힘 높이 검토: `NAVIMRO_module_only_collapsed_revC.step`
- 중립 자세 기준 556개 이름 있는 컴포넌트, 공급자 치수에 의존하는 187개는 노란색 provisional 상태다.
- 전체/접힘/중립/상승/분해 STEP와 8개 하위 조립체 STEP를 포함한다.
- 역수입 검증에서 neutral STEP는 722 solids, module-only collapsed STEP는 664 solids로 정상 복구됐다.
- module-only 접힘 외형은 900 x 800 x 292 mm다.
- 전체 테스트 132개 통과.

상세 근거와 수정 이력은 `design_basis/fusion360_detailed_cad_revC_2026-08-27.md`에 있다. Fusion 360에서 STEP를 연 뒤 필요하면 F3D로 저장한다. 노란색 부품은 공급자 STEP 또는 입고 실측값으로 교체하기 전까지 가공 승인하지 않는다.

2026-08-28 Fusion 실물 검토에서 액추에이터 조립부는 표시만 불명확한 것이 아니라 실제로 미완성임을 확인했다. 6 mm U/H 브래킷에 M8 피벗이 들어가고, U/H가 한 덩어리이며, 핀 구멍이 없는 솔리드와 프레임/액추에이터 간 큰 교차가 존재한다. 상세 판정과 수정 게이트는 `design_basis/fusion360_actuator_joint_review_2026-08-28.md`를 따른다. 현재 Rev C 액추에이터부로 발주·가공하지 않는다.

## Fusion 360 상세 CAD Rev D

Rev D는 Rev C의 액추에이터 체결 오류를 수정한 이전 검토 기준이다. 전체 조립성 수정은 아래 Rev E를 따른다.

- U/H 가상 스택을 제거하고 JFT-8R 6개, 실제 Ø8/Ø8.2 관통부, 스페이서, M8 피벗과 잠금너트를 개별 부품으로 모델링했다.
- 각 끝단은 `NVR-P03/P04` 받침판에 `NVR-P16` 러그 2장을 지그 정렬 후 용접하는 이중 전단 요크다.
- 하부 액추에이터 지지 프로파일은 640 mm, 상부 엔드/크로스 프로파일은 660 mm로 연결면까지 닿게 수정했다.
- 접힘, 중립, 상승, 최대 pitch, 최대 roll, 최대 pitch+roll 6개 자세에서 액추에이터와 상·하부 프레임의 솔리드 교차가 없다.
- 액추에이터 1번만 분리한 `ACT1_complete_mounting_cassette_neutral_revD.step`을 함께 제공해 핀과 요크 조립을 확인할 수 있다.
- 제작 해제 전 확인 항목은 A2 양단 M8 암/수 형상, 실제 핀 중심 길이, JFT-8R 입고 치수, M8 어깨부 길이와 공급자 STEP다.

상세 근거는 `design_basis/fusion360_actuator_joint_rebuild_revD_2026-08-28.md`에 기록한다. Rev D 패키지는 `output/NAVIMRO_Fusion360_detailed_CAD_revD.zip`, Fusion 권장 파일은 `outputs/navimro_fusion360_revD/step/NAVIMRO_detailed_neutral_revD.step`이다.

## Fusion 360 상세 CAD Rev E

Rev E는 Rev D 전체 조립체를 B-rep 교차시험과 조립 순서 관점에서 다시 검증한 현재 기준이다.

- Z 0~100 mm를 10 mm 간격으로 검사하고 중간 높이의 pitch/roll 최대 자세를 더한 14개 자세에서 가이드와 중앙부의 의도하지 않은 솔리드 교차가 없다.
- 상부 중앙 프로파일 관통, 교차 카단 핀, 잘못 놓인 SK12, 무가공 LMF/SK/상판 구멍, 부싱을 통과해야 했던 축 칼라와 제작 불가능한 50 x 64 스토퍼를 수정했다.
- 현재 가이드는 230 mm 축 2개, 고정 LMF12UU 4개, 이동 SK12 2개, 단일 240 mm 캐리지와 50 mm 평철 절단품으로 만든 독립 기계식 스토퍼를 사용한다.
- 직렬 카단 두 축은 Z 방향으로 12 mm 떨어져 있고 솔리드 간격은 4 mm다. 상/하 브리지는 각각 캐리지와 상부 중앙 레일에 0 mm 접촉한다.
- 명령 끝점의 스토퍼 여유는 접힘/상승 모두 2 mm이고 연결 전 모듈 포락체는 900 x 800 x 300 mm다.
- 카트 결합 그룹은 실제 카트 치수가 없으므로 모듈 아래에 분리된 provisional 참조로만 표시하며 조립 통과 판정에서 제외한다.
- 현재 가격이 있는 나비엠알오 소계는 VAT 포함 2,687,993원이다. 정확한 M4 LMF/SK 체결품, 상판 압축 슬리브와 모터 TVS가 주문행으로 확정되기 전에는 일괄 발주하지 않는다.

검증 근거와 조립 순서는 `design_basis/fusion360_assembly_validation_revE_2026-08-28.md`에 있다. 전달 패키지는 `output/NAVIMRO_Fusion360_detailed_CAD_revE.zip`, Fusion 권장 파일은 `outputs/navimro_fusion360_revE/step/NAVIMRO_detailed_neutral_revE.step`이다.

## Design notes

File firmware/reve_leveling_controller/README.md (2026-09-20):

# Rev E Mega2560 controller

This firmware is for the stationary, supervised Rev E proof-of-concept only. It is not a safety controller and it must not be used for a person-carrying or moving platform.

## Fixed interfaces

| Function | Mega2560 pins |
|---|---|
| Encoder A | D2, D3, D18 |
| Encoder B | D22, D23, D24 |
| MDD10A PWM | D5, D6, D7 |
| MDD10A direction | D30, D31, D32 |
| Unused fourth MDD10A channel | PWM D8 held at 0, direction D33 low |
| MPU6050 | SDA D20, SCL D21 |

Motor power does not pass through the Mega. The Mega, MPU6050, and encoder logic use the regulated 5 V branch. All logic grounds and the MDD10A signal grounds meet at the 5 V/24 V DC common terminal; protective earth does not carry logic current.

## Commands

Send newline-terminated commands at 115200 baud.

```text
STATUS
HOME
JOG <axis 1..3> <signed_mm>
LIFT <absolute_mm 0..50>
LEVEL
STOP
ZERO_IMU
SAVE_CAL <c1> <c2> <c3> <dL1/dP> <dL2/dP> <dL3/dP> <dL1/dR> <dL2/dR> <dL3/dR>
```

`counts/mm` must be measured on the exact actuator revision. The nominal CAD sensitivity seed at Z=25 mm is:

```text
dL/dPitch = -0.194842, 3.006702, -2.811860 mm/deg
dL/dRoll  =  3.359349,-1.510936, -1.848413 mm/deg
```

Do not use the seed as proof of real calibration. `SAVE_CAL` stores measured counts/mm and the reviewed sensitivity matrix in EEPROM. Automatic motion remains blocked until valid positive counts/mm values exist.

## Commissioning order

1. Keep motor power disconnected and verify that all PWM outputs remain at zero after reset.
2. Connect one actuator and one driver channel only.
3. Confirm motor polarity and encoder sign with short, unloaded JOG trials.
4. Run supervised HOME. Internal actuator limits are assumed; no-pulse during HOME is only an endpoint indication, not independent safety protection.
5. Measure counts/mm over at least 50 mm in both directions and record backlash.
6. Save calibration, then repeat for the remaining axes.
7. Test `LIFT 25`, `LIFT 50`, and `LEVEL` unloaded before adding the 10 kg test load.

The firmware implements PWM ramping, 100 ms reversal dead time, motion timeout, encoder no-pulse and wrong-direction faults, IMU stale detection, a 5 degree tilt fault, 0-100 mm actuator travel limits, and sequential 0.25 mm leveling corrections. The physical mechanical stops and actuator internal limits remain mandatory and independent.

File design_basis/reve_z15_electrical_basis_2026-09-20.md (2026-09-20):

# Rev E Z+15 electrical selection basis — 2026-09-20

## Decision

The least-complex electrical architecture for the approved self-weight PoC is a laptop-commanded Portenta Machine Control with two separate communication branches: its J5 RS-485 daisy chain exclusively for three DMC-200 units, and Ethernet through one isolated gateway exclusively for two HWT905 Modbus RTU sensors. It eliminates the HMI and `IF01`; it does not eliminate the independently interrupted motor 24 V branch.

```text
Laptop USB -> PC01 Portenta
                   |- J5 RS-485 -> DMC-200 #1 -> #2 -> #3
                   `- Ethernet -> SG01 tGW-715i-T (TCP 502) -> HWT905 #11/#12
E-stop NC -> rated 24 VDC contactor/disconnect -> DMC motor 24 V feed
```

The Portenta is the Modbus TCP client/master. `SG01` has a static IP and is a TCP server/slave on TCP 502, then the RS-485 Modbus RTU master. Each HWT905 is configured alone, settings saved, power-cycled and read back before the two-device bus is formed. DMC address 1/2/3 and IMU decimal ID 11/12 are fixed in the commissioning record.

## Current basis, not an approval

The supplied LM4075OE-1075 table states 24 V no-load 0.4 A and loaded 1.5 A per axis. No measured or supplier-confirmed stall curve is available. Therefore 7.5 A/axis is only a provisional sizing assumption:

```text
3 x 7.5 A = 22.5 A provisional simultaneous peak
22.5 A x 1.25 = 28.125 A selection requirement
=> 24 V, 30 A class motor PSU basis
```

DMC-200's stated 8 A continuous capacity is compatible with the 1.5 A nominal loaded datum per axis, but it does not confirm peak-duration behaviour, fuse coordination, cable gauge, contactor rating, bus regeneration or actuator compatibility. In particular, the DMC-200 ↔ LM4075OE 5 V A/B 6 ppr feedback interface must prove the DMC 5 V encoder supply/output current, A/B logic/pull-up compatibility, resolution/count scaling, three-node address/multidrop configuration and reverse escape after an internal limit. The gateway contribution is small (tGW-715i-T nominal 0.07 A at 24 V) but control-current allocation is not released until Portenta, IMU, encoder, relay/contactor coil and protection data are summed from final part data sheets.

## Motion and response expectations

The Portenta must impose a bounded JOG envelope and a command-session timeout. Session loss, invalid command acknowledgement, stale sensor data, wrong address, malformed response, or network disconnect causes all-axis control STOP request, a latched fault, CSV event record and a fresh laptop `START` requirement after reconnection. This is a control rule only. Because retained DMC command and watchdog response after a Portenta hang/motion-bus loss are unknown, motor power remains independently interruptible with E-stop.

Normal HOME does not contact an internal actuator limit. It uses only valid saved position, physical `Z=15` datum offset and no-manual-move evidence. `COMMISSIONING_HOME` or recovery is block-supported and supervised; it may search limits but must not automatically enable LEVEL afterwards. The command range is physical Z=15~65 mm, with a provisional 218~292 mm absolute pin-length software window. This has no mechanical-stop function.

## Gate list

| Gate | Closure evidence required |
|---|---|
| `HOLD_ACTUATOR_SWITCH_POINTS` | Three physical `L_low_switch` / `L_high_switch` measurements, reverse-escape check, then re-run Z/pin/collision review. |
| `HOLD_ACTUATOR_PEAK_STALL_CURVE` | Written supplier or measured 24 V peak/stall current, duration and duty curve. |
| `HOLD_DMC_ENCODER_MULTIDROP_COMPATIBILITY` | Bench and supplier evidence for DMC-200 ↔ LM4075OE 5 V A/B 6 ppr supply/output current, logic/pull-up, count scaling, address 1/2/3 three-node multidrop settings, and reverse escape after internal limit. |
| `HOLD_DMC_STOP_BEHAVIOR` | Bench fault injection: Portenta reset/hang and motion-bus unplug response, confirmed DMC retained-command/watchdog result. |
| `HOLD_SG01_QUOTE_CARD_STOCK` | Domestic VAT-included price, card purchase route, inventory and lead-time evidence for tGW-715i-T. |
| `HOLD_SMPS_30A_SKU` | Exact 24 V 30 A-class SKU with continuous rating, input/protection details and applicable certification. |
| `HOLD_ESTOP_DC_INTERRUPTION_RATING` | Selected disconnect device's 24 VDC inductive interruption rating, coil suppression and wiring/branch fuse basis. |
| `HOLD_BENCH_VERIFY` | Two-sensor 20 Hz, latency/freshness, reconnect and control-loop bench evidence. |
| `HOLD_PHYSICAL_CABLE_GUIDE_VERIFICATION` | Cable travel, strain relief and central-guide clearance at physical Z=15~65. If it fails, retain datum and cap command Z at 35 mm. |
| `HOLD_NO_INDEPENDENT_MECHANICAL_STOPS` | This is an intentional user-requested deviation, not a closable electrical claim; project purchase/fabrication release remains false until the project mechanical-stop rule is satisfied. |

## Explicit exclusions

This is not a final wiring drawing, code release, purchase release, fabrication release or field-safety assertion. It is for an indoor, supervised, no-cart/no-payload/no-person self-weight demonstration only.

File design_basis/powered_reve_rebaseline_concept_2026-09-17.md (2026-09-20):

# 전동 3-RPS Rev E 최소변경 개념설계

## 1. 결정

승인안은 기존 `POWERED_PROFILE_RADIAL_3RPS_REVE_POC_RC1`을 최대한 재사용하는 3축 전동식 수평유지 모듈이다. 2026-09-20 Z+15 명령 기준점 결정에 따라 기본 CAD 외곽은 케이블·전장함·E-stop 및 기타 전기 돌출부를 제외하고 700×700×315 mm이며, 명령 Z 0~50 mm와 pitch/roll 동시 ±3°를 유지한다. 명령 Z=0은 pitch=0°, roll=0°에서 물리 Z=15 mm이고, 명령 Z=0~50 mm는 물리 Z=15~65 mm에 대응한다. 상세 결정과 미검증 항목은 `verification/reve_z15_rebaseline_decision_2026-09-20.md`를 기준으로 한다.

새 기구를 설계하지 않고 다음만 변경 검토한다.

1. 주요 구매처를 엘레파츠 중심으로 재구성한다.
2. 기존 THK PHS6 후보를 엘레파츠의 LDK PHS 6로 대체 가능한지 검증한다.
3. 무스토퍼안은 사용자 요청을 평가하는 분석형으로만 유지한다. 구매 가능한 릴리스형에는 기존 Rev E의 독립 스토퍼를 복원하고 형상·접촉하중·체결·간섭·비용을 다시 검증한다.
4. 내장 리미트 HOME, 소프트웨어 운전창, 독립 비상정지로 제어 요구를 갱신한다.
5. 조밀 시작집합의 공통 HOME 순차/교대 경로와 변경 조인트를 포함해 간섭검증을 반복한다.

## 2. 범위

포함 범위는 상·하부 프로파일 프레임, 3개 액추에이터와 조인트, 최소 어댑터 3개, IMU 자동수평 제어, 220 VAC/24 VDC 전장, 배선, 비상정지와 시험·기록이다.

카트, 카트 본체, 적재물, 사람, 바퀴, 주행장치, AMR/AGV, 배터리, 자율주행과 카트 래치는 제외한다.

## 3. 기구학

세 하부 R축과 세 상부 S조인트는 각각 120° 간격으로 배치한다. 상부 프레임은 세 액추에이터의 길이로 평면을 결정한다. 세 축의 동일 길이 변화는 Z 이동을 만들고 길이 차이는 pitch와 roll을 만든다. R축 방향 구속과 세 링크의 공간배치가 독립 X, Y, yaw 자유도를 제거한다.

하부 조인트 중심을 `b_i`, 상부 로컬 조인트 중심을 `u_i`, 상부 위치를 `t`, 회전행렬을 `R`이라 하면 액추에이터 핀 간 길이는 다음과 같다.

```text
l_i = || t + R u_i - b_i ||
```

각 R축의 접선 단위벡터를 `q_i`라 하면 3-RPS 구속조건은 다음과 같다.

```text
(t + R u_i - b_i) · q_i = 0,  i = 1..3
```

좌표계는 하부 중심을 원점으로 하고 +X 우측, +Y 전방, +Z 상방으로 한다. roll은 X축 회전, pitch는 Y축 회전, yaw는 Z축 회전이다.

## 4. 운동범위와 여유

기존 실제 액추에이터 STEP을 사용한 27자세 검사 결과는 다음과 같다.

| 항목 | 결과 |
|---|---:|
| 검사 자세 | Z 0/25/50 mm × pitch -3/0/+3° × roll -3/0/+3°, 27개 |
| 최소 핀 간 거리 | 210.771741 mm |
| 최대 핀 간 거리 | 276.937115 mm |
| 기존 STEP 명목 물리 핀 간 범위 | 205~305 mm, 리미트 작동점 아님 |
| 최소 수축측 여유 | 5.771741 mm |
| 최소 신장측 여유 | 28.062885 mm |
| PHS6 최대 편각 | 4.096369° |
| 예상 밖 모델 간섭 | 0건 |

이 `PASS-DIGITAL` 성격의 결과는 기존 Rev E 조인트 형상에만 적용된다. LDK PHS 6와 LMB-10 실치수를 반영한 변경형에는 자동 승계되지 않으며 재검사가 필요하다. 또한 27개 꼭짓점은 연속 운전영역을 증명하지 않으므로 상세검사에서는 `Z=0:5:50 mm`, `pitch/roll=-3:0.5:+3°` 조밀 격자와 명령·HOME 경로 선분을 표본화한다.

기존 27자세의 Z=0 기준과 현행 명령 기준을 혼동하지 않는다. 현행 명령 Z=0은 pitch=0°, roll=0°에서 물리 Z=15 mm이며, 명령 Z=0~50 mm는 물리 Z=15~65 mm에 대응한다. 이 명령영역의 명목 요구 핀 길이 범위는 221.281~289.523 mm다. 각 축의 실제 내장 하한/상한 리미트 작동 핀 길이를 `L_low_switch`, `L_high_switch`로 측정한다. 205~305 mm 값은 기존 CAD/STEP의 명목 형상 범위일 뿐이며 검증된 내장 리미트 스위치 작동점이 아니다. `COMMISSIONING_HOME` 또는 감독하 복구의 리미트 탐색 뒤에는 물리 Z=15 mm의 명령 Z=0 기준점으로 이동하며, 이 감독하 동작의 축별 상승량은 실측 `L_low_switch`와 해당 기준점의 실측/검증된 핀 길이 차로 정한다. 일반 HOME은 유효하게 저장된 위치 상태와 무이동 조건을 검증한 경우에만 이미 저장된 물리 Z=15 mm 기준점으로 복귀하며, 어느 내장 리미트도 의도적으로 탐색하거나 접촉하지 않는다.

잠정 소프트웨어 보호창은 절대 핀 길이 218~292 mm다. 감독하 리미트 탐색 뒤의 상대 연장량은 축별 `[218−L_low_switch, 292−L_low_switch]`로 파생한다. 실제 허용 자세 명령은 명령 Z 0~50 mm(물리 Z=15~65 mm), pitch/roll ±3°의 역기구학 결과가 이 창 안에 있을 때만 실행한다. 정상 운전은 내장 리미트에 의도적으로 접촉하지 않아야 하며, 자동운전 전에 시운전에서 실제 `L_low_switch`와 `L_high_switch`를 기록해야 한다. 실측 스위치 길이를 입력한 뒤 스트로크·HOME·스토퍼 검사를 재실행한다. 이 창은 독립 기계식 스토퍼가 아니며 엔코더 오류나 구조 파손에 대한 안전장치로 표현하지 않는다. 최종 가이드 겹침 또는 전체 CAD 스크리닝이 실패하면 물리 +15 mm 기준은 유지하되 명령 Z 상한을 35 mm로 제한한다.

## 5. 속도 검토

Z 0/25/50 mm와 pitch/roll ±3°에서 수치미분한 결과는 다음과 같다.

- pitch/roll 합성 각속도 크기 1°/s: 최대 축속도 약 3.706 mm/s
- pitch와 roll이 각각 동시에 1°/s: 최대 축속도 약 5.122 mm/s
- 후보 액추에이터 속도: 10 mm/s

수용시험의 외란 한계는 합성 각속도 `sqrt(pitch_rate²+roll_rate²) ≤ 1°/s`다. pitch와 roll이 각각 동시에 1°/s인 조건은 수용조건이 아니라 기구·속도 스트레스 스크리닝이다. 가장 보수적인 스크리닝에서도 속도비는 약 `10/5.122 = 1.95`다. 이는 가속, 마찰, 지연과 제어오차를 제외한 기구학 여유이며 실제 추종성능의 보증값은 아니다.

## 6. 하중 검토

현행 시연은 상부 프레임과 장착부품의 자중만 사용한다. 실제 이동질량 `m_u`는 조립 후 측정한다. 구매 전 스크리닝에는 기존 보수 입력 20 kg과 불균형·동적 계수 2.0을 남긴다.

```text
F_axis,screen = 2.0 × m_u × g / 3
```

`m_u=20 kg`, `g=9.81 m/s²`이면 축당 약 130.8 N이고 750 N 후보 액추에이터 대비 정적 스크리닝 비는 약 5.7이다. 이는 인증용 안전율이 아니며 조인트, 편심, 좌굴, 충격 및 브래킷 강도를 대신하지 않는다.

## 7. 구조와 제작

- 하부: 4040 프로파일, 기존 길이와 직교 브래킷 유지
- 상부: 3030 프로파일, 기존 길이와 직교 브래킷 유지
- 하부 액추에이터 연결: LMB-10 + A6061-T6 120×70×8 mm 어댑터 3개
- 상부 액추에이터 연결: M6 로드엔드 PHS 6와 횡핀
- 조립: 절단 프로파일과 기성 브래킷을 볼트 체결
- 금속 전용가공: 어댑터 3개의 관통홀과 M8 탭만 유지
- 조립 보조가공: ABS 전장함의 글랜드, E-stop, 보드 고정홀은 현장 드릴 허용
- 분석형 제외: 기존 C04~C09 기계식 스토퍼와 해당 체결품
- 릴리스형 추가: C04~C09 포획판·상부 앵커·접촉바·스탠드오프와 M10 로드/너트 및 장착 체결품
- 위치계층: `잠정 소프트웨어 218~292 mm → 공급자 확인 내장 리미트 작동점 → 공차 최악 최소 1 mm 후 기계 스토퍼 → 최소 2 mm 후 구조 손상/하드엔드`
- 릴리스 하중: 한 스토퍼 선접촉+나머지 1축/2축 스톨, 상·하한 비대칭과 접촉위치/구동방향 순열을 3-RPS 정역학 또는 Jacobian 전치로 해석한다. 서비스하중은 `max(750 N, 스톨추력, 2,000 N self-lock, 계산 최대 접촉반력)`; 설계하중은 1.5배, 항복 안전율 2.0 이상, 파단 안전율 3.0 이상, 계산 변형 0.5 mm 이하, 슬롯마찰 단독 지지 금지
- 릴리스 제한: 위 위치·공차·하중, 체결품, 변경형 조밀 격자·HOME 간섭검사와 비용이 모두 반영되지 않으면 구매·제작 승인 불가

어댑터를 범용 브래킷 조합으로 대체하면 하부 핀 위치와 전체 운동학이 바뀌므로, 일정상 기존 단순 어댑터 3개를 유지하는 편이 낮은 위험이다.

## 8. 제어 상태

```text
POWER_OFF
  -> POWER_ON_SAFE(PWM=0)
  -> IDLE_UNHOMED
IDLE_UNHOMED -> VALIDATE_SAVED_POSITION
VALIDATE_SAVED_POSITION -- valid saved position + Z=15 datum + no-manual-move evidence --> MOVE_TO_Z0_DATUM -> IDLE_READY
VALIDATE_SAVED_POSITION -- invalid/missing datum or move evidence --> HOME_START_UNVERIFIED
HOME_START_UNVERIFIED -> COMMISSIONING_HOME_OR_SUPERVISED_RECOVERY -> IDLE_UNHOMED (LEVEL inhibited)
  -> JOG | LIFT | LEVEL
  -> IDLE_READY

어느 상태에서든 STOP 또는 FAULT -> PWM=0
E-STOP -> 모터 24 V 전원 물리 차단
```

LEVEL은 운전자 명령 이후에만 시작한다. 기존의 순차 0.25 mm 보정 개념을 유지해 동시 기동전류와 제어 복잡도를 줄인다. 종료 후에도 하부가 천천히 움직이는 동안 IMU 오차가 ±1.0° 수용범위를 벗어나면 추가 보정한다.

FAULT 항목은 다음을 포함한다.

- HOME 전 자동운전 명령
- 축별 소프트웨어 보호창 초과
- 일반 이동 중 엔코더 무펄스 또는 명령방향과 반대 카운트
- 이동 시간초과
- IMU 데이터 갱신정지
- 기울기 절대값 5° 초과
- 비상정지 입력 또는 모터전원 상실

## 9. 비상정지 개념

비상정지의 2NC 접점은 24 VDC 코일 릴레이/컨택터를 탈락시켜 모터 드라이버의 24 V 전원을 차단한다. Mega2560과 로그용 5 V 전원은 별도 분기로 유지할 수 있다. 두 번째 NC 접점은 제어기에 상태를 알려 래치형 E-STOP 오류를 기록한다.

릴레이/컨택터는 모터의 실제 기동·스톨전류 이상 DC 차단정격을 가져야 하며, 코일 서지 억제와 드라이버 회생에 따른 버스 과전압을 검토한다. 단순히 PWM을 0으로 만드는 소프트웨어 STOP은 물리적 비상정지를 대신하지 않는다.

## 10. HOME 위험과 검증

세 축이 모두 기존 명목 205 mm인 자세와 모두 명목 305 mm인 자세는 기존 형상에서 간섭 0으로 계산됐다. 실제 HOME/상한 검사는 축별 `L_low_switch/L_high_switch`와 공급자 하드엔드 공차를 대입해 다시 수행한다. 한 축씩 수축하는 중간 길이 조합은 기존 27자세에 포함되지 않았다.

일반 HOME은 저장된 유효 위치 상태, 저장된 물리 Z=15 mm 명령 기준점, 그리고 전원 차단 중 또는 이후에 이동이 없었다는 조건을 검증한 뒤 그 기준점으로 복귀하는 동작이며, 내장 리미트를 의도적으로 탐색하거나 접촉하지 않는다. 이 조건 하나라도 충족하지 않으면 `HOME_START_UNVERIFIED`로 거부한다. 상부는 3-RPS 구속을 만족하는 자세만 취할 수 있으므로, 세 길이에서 6개 플랫폼 변수 `x,y,z,pitch,roll,yaw`를 푸는 전진기구학과 각 중간 자세의 조인트 편각·간섭검사가 구매 전 필수다. 보유 블록으로 지지한 감독하 `COMMISSIONING_HOME` 또는 `HOME_START_UNVERIFIED` 복구에서만 수행할 리미트 탐색 경로의 시작집합은 명령 `Z=0:5:50 mm`(물리 Z=15:5:65 mm), `pitch/roll=-3:0.5:+3°` 조밀 격자, 모든 허용 명령·JOG 경로 표본과 후보 리미트 탐색 중간상태 전체다. 각 중간상태에서 동일 경로 재시작도 검사한다. 모든 시작점에 공통으로 적용할 단일 순차 순서를 얻기 위해 세 축 모든 순열 6가지를 1 mm 이하 축길이 간격으로 검사하고, 전체 시작집합을 통과하는 순서 중 최대 기울기와 편각이 가장 작은 하나를 채택한다. 순차 공통순서가 없으면 A1/A2/A3의 6개 순환순서로 1 mm 교대수축을 검사해 공통순서 하나를 선택하며, 이것도 없으면 복구 HOME 설계를 변경한다. 이 감독하 동작 뒤에는 자동 LEVEL을 시작하지 않으며, 일반 HOME의 조건을 다시 충족·검증하기 전까지 LEVEL을 금지한다.

일반 운전의 no-pulse는 즉시 고장이다. 내장 리미트 탐색은 감독하 `COMMISSIONING_HOME` 또는 `HOME_START_UNVERIFIED` 복구에만 허용한다. 그때의 접근속도는 `1.0±0.2 mm/s`로 하고 실제 `HOME_PWM`은 속도교정값으로 저장한다. no-pulse 시간은 예상 펄스주기의 3배와 500 ms 중 큰 값, 최대 2,000 ms다. 내장 리미트 상태신호가 없으면 축별 전류센서를 사용해 명령 중 no-pulse와 `I_axis < 0.1×I_home_run`이 함께 나타날 때만 개방 리미트 후보로 보고, `I_axis > 1.5×I_home_run` 또는 드라이버 전류제한은 걸림 FAULT로 본다. 이후 2 mm 탈출≥기대카운트 90%와 2회 재접근 종단차 `max(1 count, 0.25 mm×counts_per_mm)` 이내를 모두 요구한다. 전류/리미트 상태를 읽을 수 없으면 감독하 복구도 허용하지 않는다.

저장된 마지막 자세가 없거나 수동 이동 가능성이 있거나 감사 시작집합 포함 근거가 없으면 `HOME_START_UNVERIFIED`로 자동 HOME을 거부하고, 보유 블록으로 지지한 감독하 복구절차에서만 리미트 탐색을 사용한다. 저장된 유효 위치 상태가 있는 경우에만 일반 HOME으로 물리 Z=15 mm 명령 기준점에 복귀할 수 있다.

최초 조립은 별도 `COMMISSIONING_HOME`으로 처리한다. 전원 차단·블록 지지 상태에서 세 핀 길이를 ±1 mm로 실측해 감사 시작상태임을 확인한 뒤, 모터전원 릴리스 후 한 축씩 10 mm 자유구간을 전류제한 JOG하여 `HOME_PWM`과 `I_home_run`을 교정한다. 각 축 하한 리미트·2 mm 탈출·2회 재접근을 확인한 뒤 공통 감독하 리미트 탐색을 실행하고 실제 `L_low_switch`, `L_high_switch`, counts/mm, 물리 Z=15 mm의 명령 Z=0 오프셋과 마지막 자세를 비휘발성 저장한다. 이 기록 전에는 자동운전을 허용하지 않는다.

조밀 격자는 연속영역의 해석적 증명이 아니라 스크리닝이다. pose-space 축 인접점을 다른 두 좌표 고정 상태에서 Z 1 mm 이하 또는 각도 0.1° 이하 간격으로 선형 보간하고, 동시 명령도 시작·끝 pose를 같은 최대 간격으로 표본화한다.

## 11. 구매처 결정

엘레파츠에서 액추에이터, LMB-10, PHS 6, 프로파일, 모터드라이버, Mega2560, MPU6050, DC-DC, 비상정지 및 배선부품을 한 장바구니로 구성할 수 있다. 다만 액추에이터와 일부 조인트는 주문수입 또는 납기문의 품목이고, 24 V 14.6 A급 전원은 후보 SKU의 재고가 불안정하다.

따라서 구매정책은 다음과 같다.

1. 엘레파츠 단일장바구니를 우선한다.
2. 핵심 SKU, 전원 또는 가공품을 엘레파츠에서 확보하지 못할 때만 두 번째 국내 구매처 한 곳을 사용하며 총 구매처는 2곳을 넘지 않는다.
3. 액추에이터 3개는 기본견적, 네 번째는 선택견적으로 분리한다.
4. 주문수입품은 옵션과 납기를 서면확인한 뒤 결제한다.

독립 스토퍼 릴리스형의 기본안과 예비 액추에이터 포함 선택안은 각각 구조·전장·가공·배송비를 포함해 4,000,000원 이하여야 한다. 24 V 14.6 A 전원과 24 VDC 20 A 컨택터는 비교용 1차 후보일 뿐이다. 실제 기동·스톨전류와 아래 정격기준이 확인되기 전에는 용량 적합 또는 구매 가능으로 판정하지 않는다. 액추에이터의 2,000 N self-lock 표기도 실제 설치자세의 정적 유지·역구동 조건에 대한 공급자 답변과 대조한다.

| 회로 요소 | 설계전류 기준 |
|---|---|
| 드라이버 채널 | 연속 ≥ 축 정격전류×1.25, 피크 ≥ 축 스톨전류와 허용시간 |
| 축 퓨즈·배선 | 정상 기동곡선 통과, 퓨즈 정격은 배선 허용전류 이하 |
| PSU | 순차제어 정상 최악 동시구동 전류와 제어전류 합×1.25 이상 |
| 주배선 | 세 축 분기퓨즈와 제어분기 정격 합 이상 |
| E-stop 컨택터 | 24 VDC 유도성 부하 제조사 차단정격이 세 축 스톨전류 합×1.25 이상 |
| 회생 | 최대 감속/하강 버스전압이 PSU 허용값 이내, 초과 시 클램프/덤프 추가 |

## 12. 수용시험 기준

- 제어 및 로그 표본률: 20 Hz 이상, 원시값과 1초 이동평균 보존
- 시간동기: 상부 제어·하부 계측은 동일 Mega2560 `micros()` 사용. 독립 상부 기준계는 TTL 또는 공통 동기 이벤트로 정렬하며 시험 전후 timestamp skew 25 ms 이하
- 계측성능: 상부 기준계 ±5° 구간 정확도 ±0.2° 이하, 분해능 0.05° 이하; -3°/0°/+3°에서 축·부호·영점 확인, 잔여 영점오차 0.2° 이하
- 정적: 독립 상부 기준계의 1초 이동평균으로 하부 정지 후 5초 이내 두 축 동시 ±1.0° 진입, 10초 유지; ±0.5°는 목표
- 동적: 하부 전용 IMU/경사계로 합성 각속도 1°/s 이하를 확인. 하부 운동 개시(0.1°/s 초과) 2초 후부터 상부 독립 기준계의 동시충족 표본이 90% 이상이고, 기준계 원시값은 어느 축도 2.0°를 초과하지 않음
- 기준계측: 상부 제어 IMU와 독립된 상부 기준계 사용. 미확보 시 `POC_ACCEPTANCE=PROVISIONAL`

## 13. 단계별 릴리스와 현재 판정

- 구매 릴리스: 독립 스토퍼 릴리스형, 공급자 자료, BOM, 기본·선택 예산을 포함한 G0~G9 종료 후
- 제작 릴리스: LMB/PHS 실치수, 어댑터·스토퍼 도면, 변경형 조밀 격자·명령선분, HOME 경로 통과 후
- 제어전원 시험 릴리스: 모터·드라이버 출력 분리, 무전원 도통·단락, 보호접지, 분기퓨즈 확인. 컨택터 전력입력에 1 A 제한 24 V 시험전압을 인가해 E-stop 해제 출력은 입력±5%, 작동 1초 후 출력은 1.0 V 이하인지 무부하 확인
- 모터전원 릴리스: E-stop 무부하 컨택터 시험에서 출력버스 0 V, PWM/드라이버 출력 0, 극성·퓨즈·전류제한을 확인한 후 축별 저속 JOG부터 허용

| 항목 | 상태 |
|---|---|
| 개념 | 승인 |
| 기존 27자세 운동학·간섭 | LEGACY PASS, 변경 조인트·스토퍼 릴리스형에는 미적용 |
| 동일길이 물리 양단 자세 | LEGACY PASS, 변경형 OPEN-CAD |
| 공통 HOME 순차/교대 경로 | 미검증 |
| LDK PHS 6 실제대체 | 미검증 |
| LMB-10 실제치수 | 미확정 |
| 액추에이터 전기정보 | 미확정 |
| 비상정지 부품 정격 | 미확정 |
| 실물 조립·가동 | 미실시 |
| 독립 기계식 스토퍼 릴리스형 | BOM 계획비만 반영, CAD·하중·간섭·견적 미검증으로 릴리스 차단 |
| 구매 릴리스 | 보류 |
| 제작 릴리스 | 보류 |
| 제어전원 시험 릴리스 | 보류 |
| 모터전원 릴리스 | 보류 |

## 14. 주장 제한

이 문서는 상세 설계의 기준선이다. 사람 운반, 적재물 운반, 인증, 현장 안전, 고장 시 안전 또는 장기 내구성을 입증하지 않는다.

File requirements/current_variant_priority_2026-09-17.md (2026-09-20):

# 2026-09-17 승인 기준 — 전동 3-RPS Rev E 최소변경

## 상태

사용자는 2026-09-17 `APPROVE CONCEPT`를 입력하여 아래 개념을 승인했다.

```text
CONCEPT_APPROVED = TRUE
PRIORITY_1 = POWERED_PROFILE_RADIAL_3RPS_REVE_MINIMAL_CHANGE
PRIORITY_2 = MANUAL_M2R2_S220_HISTORICAL_REFERENCE_ONLY
PURCHASE_RELEASE = FALSE
FABRICATION_RELEASE = FALSE
CONTROL_POWER_TEST_RELEASE = FALSE
MOTOR_POWER_RELEASE = FALSE
POC_ACCEPTANCE = FALSE
```

개념 승인은 상세 설계와 구매 준비를 진행해도 된다는 뜻이다. 공급자 서면답변, 변경부품 치수, HOME 경로 간섭, 전원 차단회로와 최종 장바구니 검토가 닫혔다는 뜻은 아니다.

## 승인 요구사항

| 항목 | 승인 기준 |
|---|---|
| 시연 범위 | 카트·적재물·사람 없음, 상판 없는 공개형, 상부 모듈 자중 전용 |
| 기구 | 120° 방사형 3-RPS, 기존 Rev E 최소변경 |
| 허용 자유도 | Z 이동, pitch, roll |
| 구속 자유도 | 상·하부 사이의 독립 X, Y, yaw |
| Z 명령범위 | 0~50 mm |
| 각도 명령범위 | pitch/roll 동시 ±3° |
| 외란 | 하부 프레임을 사람 또는 보유 블록으로 천천히 기울임 |
| 외란 속도 | 수용시험은 합성 각속도 `sqrt(pitch_rate²+roll_rate²) ≤ 1°/s`; 각 축 동시 1°/s는 기구·속도 스트레스 스크리닝에만 사용 |
| 자동수평 | 운전자가 LEVEL 명령을 내린 뒤 IMU 폐루프로 수평 유지 |
| 성능 목표 | 정상상태 ±0.5°, 시제품 수용기준 ±1.0° |
| 시동 상태 | 전원 인가와 리셋 후 모든 PWM=0, 자동운전 시작 금지 |
| 운전자 인터페이스 | 노트북 USB/시리얼 명령 및 상태·고장 로그 |
| 명령 | STATUS, HOME, JOG, LIFT, LEVEL, STOP, ZERO_IMU, SAVE_CAL |
| HOME | 일반 HOME은 저장된 유효 위치 상태, 저장된 물리 Z=15 mm 기준점, 무이동 조건을 검증한 뒤 그 기준점으로 복귀하며 내장 리미트를 의도적으로 탐색·접촉하지 않음; 조건 미충족 시 `HOME_START_UNVERIFIED`로 거부하고, 리미트 탐색은 블록 지지 감독하 시운전 또는 복구에 한정 |
| 범위 초과 | 명령 거부, 모터 정지, 래치형 오류 |
| 비상정지 | 노트북과 독립된 물리식 버튼으로 모터 24 V 전원 차단 |
| 전원 | 실내 220 VAC 사용 가능 |
| 조달 | 엘레파츠 단일 장바구니 우선, 핵심 SKU·전원·가공품 중 불가 품목이 있으면 두 번째 국내 구매처 1곳만 허용(총 2곳 이하) |
| 제작 | 절단 프로파일과 볼트 조립 우선, 명확한 이점이 있을 때 드릴·탭 허용 |
| 전용 가공 | 무스토퍼 분석형은 어댑터 3개만, 구매 가능한 릴리스형은 독립 스토퍼용 판·스탠드오프를 추가; ABS 전장함의 글랜드·E-stop·고정홀 현장 드릴은 조립 보조가공으로 허용 |
| 구매 방식 | 1축 선구매 없이 3축 일괄구매, 예비 액추에이터 1개는 선택견적 |
| 총예산 | 구조·전장·가공·배송 포함 기본안과 예비 액추에이터 포함 선택안 모두 4,000,000원 이하 |
| 결과보고 | 2026년 11월 말, 사진과 과정 기록 필수 |

## 안전 편차

사용자는 별도 기계식 스토퍼를 설치하지 않고 액추에이터 내장 리미트만 사용하기로 결정했다. 이 결정은 일반 기계 안전 설계 또는 본 프로젝트의 기본 공학 규칙을 충족한 것으로 표현하지 않는다. 특히 현행 프로젝트 규칙은 전기 리미트와 독립 기계식 스토퍼의 분리를 요구하므로, 무스토퍼 상태는 구매·제작 릴리스를 막는 요구사항 충돌이다.

허용 범위는 다음에 한정한다.

- 카트·적재물·사람이 없는 감독하 실내 자중 시연
- 액추에이터 내장 상·하한 리미트의 서면 사양 확인
- 엔코더 기반 소프트웨어 운전창과 5° 기울기 오류 정지
- 무펄스, 역방향, 시간초과, IMU 갱신정지 감시
- 독립 물리식 비상정지에 의한 모터전원 차단
- 작업자의 손과 공구가 가동영역 밖에 있는 상태에서만 구동

사람 탑승, 적재물 운반, 현장 안전, 인증 적합성 또는 고장 시 안전을 주장하지 않는다.

## 기준 형번과 미확정 항목

| 구성 | 현행 후보 | 확정 전 조건 |
|---|---|---|
| 액추에이터 | LM4075OE-1075, 24 V, 100 mm, 10 mm/s, 750 N, 5 V 6 ppr | 전류, 듀티, 배선, 리미트, 3대 동시납기 |
| 하부 조인트 | LMB-10 | 핀·홀·오프셋 도면 및 핀 포함 여부 |
| 상부 조인트 | LDK PHS 6 | 기존 THK PHS6와 외형·편각·정격 대조 |
| 드라이버 | Cytron MDD10A 2개 | 액추에이터 기동·스톨전류가 채널 정격 이내 |
| 제어기 | Arduino Mega2560 | 기존 펌웨어 핀맵과 보드형상 확인 |
| IMU | GY-521/MPU6050 | 장착축, 영점 및 온도 드리프트 보정 |
| 24 V 전원 | 24 V, 약 14.6 A급 1차 후보 | 실제 기동·스톨전류 합계와 회생 시 버스전압이 확인되기 전에는 용량 적합으로 판정하지 않음 |
| 비상 차단 | 2NC E-stop + 24 VDC 20 A급 1차 릴레이/컨택터 후보 | 실제 전류에 대한 DC 차단정격, 코일 서지 억제, fail-safe 결선 확인 전에는 적합으로 판정하지 않음 |

## 좌표계와 기준점

- 원점: 하부 프레임 평면 중심
- +X: 장치 우측
- +Y: 장치 전방
- +Z: 상부 방향
- roll: +X축 회전
- pitch: +Y축 회전
- yaw: +Z축 회전
- 명령 Z=0: pitch=0°, roll=0°에서 물리 Z=15 mm인 운전기준점이며 액추에이터 물리 하한이 아님
- 명령 Z=0~50 mm: 물리 Z=15~65 mm에 대응; pitch/roll은 동시에 ±3° 유지

이 명령영역에서 명목 요구 핀 길이 범위는 221.281~289.523 mm다. `L_low_switch`와 `L_high_switch`는 각 축 내장 리미트가 실제 작동하는 핀 간 거리이며 공급자 자료와 실측으로 정한다. 205~305 mm 값은 기존 CAD/STEP의 명목 형상 범위일 뿐 검증된 내장 리미트 스위치 작동점으로 사용하지 않는다.

`COMMISSIONING_HOME` 또는 감독하 복구의 리미트 탐색 뒤에는 물리 Z=15 mm의 명령 Z=0 기준점으로 이동한다. 이 감독하 동작의 축별 상승량은 실측 `L_low_switch`와 해당 기준점의 실측/검증된 핀 길이 차로 정한다. 일반 HOME은 유효하게 저장된 위치 상태와 무이동 조건을 검증한 경우에만 이미 저장된 물리 Z=15 mm 기준점으로 복귀하며, `L_low_switch` 또는 `L_high_switch`를 찾기 위해 구동하지 않는다. 잠정 소프트웨어 핀 길이 창은 절대길이 218~292 mm이고, 감독하 리미트 탐색 후의 상대 연장량은 축별 `[218−L_low_switch, 292−L_low_switch]`로 파생한다. 정상 운전은 내장 리미트에 의도적으로 접촉하지 않아야 하며, 자동운전 전에 시운전에서 실제 `L_low_switch`와 `L_high_switch`를 기록한다. 정확한 counts/mm, 스위치 길이, 물리 Z=15 mm의 명령 Z=0 오프셋은 실물 측정 후 저장하고 스트로크·HOME·스토퍼 검사를 다시 실행한다. 최종 가이드 겹침 또는 전체 CAD 스크리닝이 실패하면 물리 +15 mm 기준은 유지하되 명령 Z 상한을 35 mm로 제한한다. 상세 기준과 미검증 항목은 `verification/reve_z15_rebaseline_decision_2026-09-20.md`를 따른다.

## 수용시험 측정 규칙

- 제어·로그 표본률은 20 Hz 이상으로 하고 원시값과 1초 이동평균을 함께 보존한다. 정적·동적 ±1.0° 합격 판정은 독립 상부 기준계의 1초 이동평균으로 하고, 2.0° 순간 한계는 같은 기준계의 원시 표본으로 판정한다.
- 상부 제어 IMU와 하부 IMU는 같은 Mega2560의 `micros()` 시간축으로 기록한다. 독립 상부 기준계는 공통 TTL 트리거 또는 세 로그에 보이는 동기 기울임 이벤트로 정렬하고, 시험 전후 확인한 timestamp skew가 25 ms 이하여야 한다.
- 독립 상부 기준계의 ±5° 구간 정확도는 ±0.2° 이하, 분해능은 0.05° 이하로 한다. 조립 후 -3°/0°/+3° 기준에서 상·하부 축방향, 부호와 영점을 확인하고 잔여 영점오차가 0.2° 이하여야 한다.
- 정적 시험은 하부 기울임을 멈춘 뒤 5초 이내에 `|pitch|≤1.0° AND |roll|≤1.0°`로 들어오고 그 상태를 10초 유지하면 수용한다. ±0.5°는 목표치이며 수용 한계가 아니다.
- 동적 시험은 하부 전용 IMU/경사계가 측정한 합성 각속도 `sqrt(pitch_rate²+roll_rate²) ≤ 1°/s`에서 수행한다. 하부 운동 개시(`합성 각속도 >0.1°/s`) 2초 후부터 운동 종료까지, 상부 기준계 표본의 90% 이상이 두 축을 동시에 `|pitch|≤1.0° AND |roll|≤1.0°`로 만족하고 어떤 원시 표본도 어느 축에서든 절대값 2.0°를 넘지 않아야 한다.
- 상부 제어 IMU와 독립된 기준 경사계/IMU를 우선 사용한다. 확보하지 못하면 `POC_ACCEPTANCE=PROVISIONAL`로만 기록하고 독립 계측 부재를 결과보고서 한계로 남긴다.

## HOME 판정 규칙

- 일반 HOME과 자동운전은 저장된 유효 위치 상태, 저장된 물리 Z=15 mm 명령 기준점 오프셋, 그리고 전원 차단 중 또는 이후에 이동이 없었다는 무이동 조건이 검증된 경우에만 허용하며, 내장 리미트 탐색 또는 접촉을 의도적으로 수행하지 않는다.
- 위 조건 중 하나라도 충족하지 않으면 `HOME_START_UNVERIFIED`로 일반 HOME과 자동운전을 거부한다. 보유 블록으로 상부를 지지한 감독하 `COMMISSIONING_HOME` 또는 `HOME_START_UNVERIFIED` 복구에서만 아래 리미트 탐색과 재접근을 수행할 수 있으며, 그 동작 뒤에는 자동 LEVEL을 시작하지 않는다. 일반 HOME 조건을 다시 충족·검증하기 전까지 LEVEL을 금지한다.

- 리미트 탐색용 HOME 시작집합은 27개 꼭짓점이 아니라 명령 `Z=0:5:50 mm`(물리 Z=15:5:65 mm), `pitch/roll=-3:0.5:+3°` 조밀 격자, 모든 허용 명령·JOG 경로 표본과 후보 리미트 탐색의 모든 중간상태다. 각 중간상태 각각에서도 동일 경로를 재시작해 안전하게 완료되는지 검사한다. 모든 시작점에 공통으로 적용할 단일 축 순서를 정하기 위해 A1/A2/A3 모든 순열 6가지를 1 mm 이하 축길이 간격으로 검사한다.
- 단일 순차 순서가 없으면 A1/A2/A3의 6개 순환순서 각각으로 세 축을 1 mm씩 번갈아 수축하는 교대 경로를 검사하고, 모든 시작점에서 통과하는 공통 순환순서 하나를 채택한다. 이것도 없으면 감독하 복구 HOME 설계를 변경하며 구매 릴리스를 유지하지 않는다.
- 일반 이동 중 엔코더 무펄스는 즉시 고장이다. 감독하 리미트 탐색의 접근속도는 `1.0±0.2 mm/s`로 고정하고 실제 `HOME_PWM`은 납품 후 속도교정으로 저장한다. `NO_PULSE_TIMEOUT_MS`는 공급자 counts/mm로 계산한 예상 펄스주기의 3배와 500 ms 중 큰 값으로 하되 2,000 ms를 넘기지 않는다.
- 감독하 리미트 탐색 중에는 위 저속·예상 방향 구동 뒤의 무펄스만 하한 종단 후보로 취급한다. 액추에이터가 리미트 상태신호를 제공하면 그 신호를 함께 요구한다. 제공하지 않으면 축별 전류센서로 `명령 중 무펄스 AND 전류가 이동평균의 10% 미만`인 개방 리미트만 후보로 인정하고, `전류가 이동평균의 150% 초과` 또는 드라이버 제한에 닿으면 걸림으로 즉시 FAULT한다. 어느 구분도 구현할 수 없으면 감독하 리미트 탐색을 허용하지 않고 외부 홈센서 추가를 변경요청으로 올린다.
- 감독하 리미트 탐색의 종단 후보 뒤 반대방향 2.0 mm 탈출에서 기대카운트의 90% 이상을 확인하고, 하한 재접근을 2회 수행해 두 종단값 차이가 `max(1 count, 0.25 mm×counts_per_mm)` 이내일 때만 종단으로 확정한다. 불일치는 걸림 또는 엔코더 고장이다.
- 증분 엔코더의 저장된 마지막 자세가 없거나, 전원차단 중 수동 이동 가능성이 있거나, 현재 상태가 위 감사 시작집합에 속한다는 근거가 없으면 `HOME_START_UNVERIFIED`로 자동 HOME을 거부한다. 이 경우 보유 블록으로 상부를 지지한 감독하 복구절차에서만 리미트 탐색을 사용한다.
- 조밀 격자는 연속영역 증명이 아니라 스크리닝이다. 조밀 격자의 축 인접점은 pose-space에서 다른 두 좌표를 고정하고 Z만 1 mm 이하 또는 한 각도만 0.1° 이하 간격으로 선형 보간한다. 동시 명령은 시작·끝 pose를 같은 최대 간격으로 선형 보간한다. 연속영역이라는 표현을 쓰려면 별도 해석적 경계증명이 필요하다.

### 최초 `COMMISSIONING_HOME`

1. 전원 차단 상태에서 상부를 보유 블록으로 지지하고 세 축 핀 중심거리를 ±1.0 mm 이내로 실측한다.
2. 실측 길이의 전진기구학 해가 감사 시작집합에 포함되고 간섭·편각·5° 한계를 통과하는지 확인한다. 통과하지 않으면 모터를 구동하지 않고 블록 지지 상태에서 자세를 복구한다.
3. `MOTOR_POWER_RELEASE` 후에도 한 축만 연결하고 전류제한을 적용한다. 자유구간 10 mm 단축 JOG에서 PWM을 단계적으로 올려 `1.0±0.2 mm/s`가 되는 `HOME_PWM`과 그 구간 전류 중앙값 `I_home_run`을 축별 저장한다.
4. 같은 축을 하한으로 접근시켜 리미트 상태 또는 저전류 개방을 확인하고, 2 mm 탈출과 2회 재접근 반복성을 확인한다. 축별로 반복한 뒤에만 세 축 공통 HOME을 실행한다.
5. 실제 `L_low_switch`, `L_high_switch`, counts/mm, 물리 Z=15 mm의 명령 Z=0 오프셋과 마지막 검증자세를 비휘발성 저장한다. 이후 일반 HOME은 저장된 유효 상태로만 기준점에 복귀하며 리미트를 탐색하지 않는다.

## 전장 설계전류 규칙

| 대상 | 최소 판정기준 |
|---|---|
| 모터 드라이버 채널 | 연속정격 ≥ `1.25×해당 축 정격전류`, 피크정격 ≥ 해당 축 실측 스톨전류와 허용 스톨시간 |
| 축별 퓨즈·배선 | 정상 기동을 허용하되 퓨즈 정격 ≤ 배선 허용전류; 실측 기동곡선과 퓨즈 시간-전류곡선 대조 |
| PSU 연속출력 | 순차제어 정상 최악조건의 `1.25×(제어전류+동시에 구동되는 축 정격전류 합)` 이상 |
| 주배선 | 세 축 분기퓨즈 정격 합과 제어분기 정격 합 이상 |
| E-stop 컨택터 | 제조사가 24 VDC 유도성 부하에서 명시한 차단정격 ≥ `1.25×세 축 실측 스톨전류 합`; 정상 순차기동과 별개인 동시고장 차단조건 |
| 회생 처리 | 최대 하강/감속 시 DC 버스전압을 측정하고 PSU 허용전압 이내임을 확인; 초과 시 클램프/덤프 회로 추가 |

## 독립 스토퍼 설계규칙

- 축길이 방향의 순서는 하한과 상한 모두 `정상 소프트웨어 한계 → 내장 전기 리미트 작동점 → 독립 기계식 스토퍼 접촉점 → 액추에이터/구조 손상 한계`여야 한다.
- 정상 소프트웨어 창은 잠정 핀 길이 218~292 mm다. 전기 리미트 작동 길이와 공차, 그 이후 하드엔드까지의 허용 오버트래블은 공급자 서면값을 사용하며 205~305 mm 값을 리미트 작동점으로 가정하지 않는다.
- 전기 리미트 작동점과 기계 스토퍼 사이 여유는 공차 최악조건에서 최소 1.0 mm, 목표 2.0 mm다. 기계 스토퍼 접촉점과 구조 손상/액추에이터 하드엔드 사이 잔여여유는 최악조건에서 최소 2.0 mm다. 공급자 오버트래블이 이 계층을 허용하지 않으면 현 스토퍼 방식은 불합격이다.
- 축별 서비스 접촉하중은 `max(액추에이터 정격추력 750 N, 실측/공급자 스톨추력, self-lock 표기 2,000 N)`로 둔다. 설계하중은 서비스 하중×1.5, 그 설계하중에 대해 항복 안전율 2.0 이상·파단 안전율 3.0 이상을 요구한다.
- 결합 고장사례는 한 스토퍼가 먼저 접촉한 상태에서 나머지 한 축 스톨, 나머지 두 축 동시 스톨, 상·하한 비대칭 접촉과 세 접촉위치/구동방향 순열을 포함한다. 3-RPS 정역학 또는 액추에이션 Jacobian 전치로 각 스토퍼 접촉반력을 구하고, 위 축별 서비스값과 결합 해석값 중 큰 값을 서비스 접촉하중으로 사용한다.
- 스토퍼는 슬롯 마찰만으로 하중을 받지 않고 양의 베어링/체결 경로를 가져야 한다. 설계하중에서 영구변형이 없어야 하며 계산 탄성변형은 0.5 mm 이하여야 한다.

## 구매 전 필수 게이트

1. 구매 가능한 릴리스형에 상·하한 위치계층과 공차, 단일축 및 한 스토퍼+나머지 1/2축 스톨 결합반력, 1.5배 설계하중, 항복/파단 안전율, 변형, 양의 하중경로, 체결품, 변경형 조밀 격자·HOME 간섭검사와 비용 반영 완료. 무스토퍼안은 분석 전용으로 유지
2. 액추에이터의 24 V/100 mm/5 V 엔코더 옵션과 3대 동시납기 서면확인
3. 내장 양단 리미트가 모터회로를 차단하고 반대 방향 탈출을 허용한다는 서면확인
4. 정격·기동·스톨전류, 듀티사이클과 배선표 확보
5. LMB-10 및 LDK PHS 6 치수도 확보
6. LDK PHS 6와 LMB-10 치수를 반영한 조립·간섭 재검토
7. 조밀 시작집합, 6개 공통 순서 및 필요 시 6개 교대 순환순서 HOME 전 경로의 자세·조인트·간섭 검토
8. 비상정지 릴레이/컨택터의 DC 차단정격과 회로 검토
9. 단일 장바구니 BOM의 수량·옵션·VAT·배송·납기·반품제한 확인
10. 독립 스토퍼 릴리스형 기준의 기본안과 예비 액추에이터 포함 선택안 모두 총액 4,000,000원 이하 확인

모든 게이트가 닫히기 전까지 `PURCHASE_RELEASE=FALSE`를 유지한다.

## 단계별 릴리스 게이트

- `PURCHASE_RELEASE`: 위 G0~G9에 해당하는 공급자·BOM·예산·독립 스토퍼 릴리스형이 모두 닫힌 뒤에만 참이다.
- `FABRICATION_RELEASE`: LMB/PHS 실치수 대입, 어댑터·스토퍼 도면 동결, 변경형 조밀 격자·명령선분 및 HOME 전 경로 검사가 추가로 통과한 뒤에만 참이다.
- `CONTROL_POWER_TEST_RELEASE`: 모터와 드라이버 모터출력을 분리한 상태에서 무전원 도통·단락, 보호접지, 분기퓨즈를 확인한다. 5 V 제어부와 24 V 컨택터 코일을 통전하고, 컨택터 전력입력에는 1 A 퓨즈/전류제한 24 V 시험전압만 인가한다. E-stop 해제 시 출력은 입력의 ±5% 이내, 작동 시 1초 후 출력은 1.0 V 이하인지 무부하 측정한다.
- `MOTOR_POWER_RELEASE`: 제어전원 시험, E-stop 무부하 차단, 드라이버 출력 0, 극성·퓨즈·전류 제한 설정을 확인한 뒤에만 액추에이터 모터전원을 허용한다. 이후에도 A1→A2→A3 축별 저속 JOG 후 3축으로 확대한다.

## 납품 후 단계

1. 전원 미인가 상태의 기구 조립 및 수동 가동영역 확인
2. 모터 분리 상태에서 도통·단락·보호접지·퓨즈 확인
3. 제어전원 시험 릴리스 후 5 V 제어와 컨택터 코일만 통전하여 E-stop 출력버스 0 V 확인
4. 모터전원 릴리스 후 축별 저속 JOG로 모터 극성과 엔코더 부호 확인
5. 축별 내장 하한 리미트와 역방향 탈출 확인
6. 50 mm 왕복 counts/mm와 백래시 측정
7. 감독하 공통순서 3축 리미트 탐색 검증과 저장된 유효 상태에서의 일반 HOME, Z 0/25/50 mm 시험
8. 정적 pitch/roll 및 복합 ±3° 시험
9. 사람이 하부를 합성 각속도 1°/s 이하로 기울이는 동적 수평유지 시험
10. 사진, 로그, 고장·수정사항을 결과보고서 자료로 보존

## 참조

- 개념설계: `design_basis/powered_reve_rebaseline_concept_2026-09-17.md`
- 공급업체 질의서: `procurement/powered_reve_eleparts_supplier_inquiry_2026-09-17.md`
- 검증 매트릭스: `verification/powered_reve_verification_matrix_2026-09-17.md`
- 기존 디지털 감사: `verification/RevE_PoC_release_candidate_audit_2026-09-04.md`
- 기존 실제 공급자 CAD: `outputs/profile_radial_revE_actual_vendor/Profile_Radial_3RPS_RevE_ACTUAL_VENDOR.f3d`

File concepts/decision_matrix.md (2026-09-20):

# 기구 대안 의사결정표

## 1. 평가 방법

각 항목을 1점(매우 불리)에서 5점(매우 유리)으로 평가하고 가중치를 곱했다. 최대값은 500점이며 100점 환산값을 함께 표시한다. 값은 Phase 1 개념 비교이며 공급업체 견적이나 상세 해석을 대체하지 않는다.

| 평가 기준 | 가중치 | A 3점 | B 4점 | C 분리형 | 핵심 근거 |
|---|---:|---:|---:|---:|---|
| 전체 수축 높이 | 10 | 4 | 3 | 1 | A가 가장 낮고 C는 3단 적층 |
| 50-100 mm 리프트 | 8 | 4 | 4 | 4 | 모두 가능하나 패키징 확인 필요 |
| Pitch/Roll 제어 | 9 | 5 | 5 | 4 | A/B 직접 평면 제어, C 축 순서 영향 |
| 액추에이터 수 | 5 | 4 | 2 | 4 | A/C 3축, B 4축 |
| 제어 난이도 | 8 | 3 | 2 | 4 | B 동기/하중균등 어려움, C 축 분리 |
| 비틀림·걸림 위험 | 10 | 4 | 1 | 5 | 3점은 평면 결정, B 과구속 |
| 기계적 안정성 | 9 | 4 | 3 | 5 | C 피벗 구속 명확, A는 삼각 지지영역 관리 |
| 제작 난이도 | 7 | 3 | 3 | 2 | C 프레임/베어링 적층 |
| 조립 난이도 | 5 | 3 | 2 | 2 | B 영점 정렬, C 축 정렬 부담 |
| 유지보수성 | 5 | 4 | 3 | 3 | A 부품 수가 적음 |
| 부품 조달 용이성 | 4 | 3 | 3 | 3 | 모두 액추에이터 사양 확인 필요 |
| 카트 결합부 공간 | 4 | 4 | 3 | 2 | B 코너 4개, C 상부 피벗과 간섭 |
| 예상 제작비 | 6 | 4 | 2 | 2 | B/C 부품 수와 가공 증가 |
| PoC 완성 가능성 | 6 | 4 | 2 | 3 | A 핵심 위험이 비교적 한정적 |
| 수정·재가공 용이성 | 4 | 4 | 3 | 2 | A 볼트 조립/좌표 변경 용이 |
| **가중 합계** | **100** | **385/500** | **276/500** | **322/500** |  |
| **100점 환산** |  | **77.0** | **55.2** | **64.4** |  |

## 2. 정량 비교 요약

| 항목 | A 3점 | B 4점 | C 분리형 |
|---|---:|---:|---:|
| 수축 높이 추정 | 270 ±15 mm | 285 ±15 mm | 325 ±20 mm |
| 완전 상승 높이 추정 | 370 ±15 mm | 385 ±15 mm | 425 ±20 mm |
| ±3°+100 mm 시 최대 액추에이터 스트로크 | 155.4 mm | 157.5 mm | Z 100 mm, Pitch 31.4 mm, Roll 26.2 mm |
| 액추에이터 수 | 3 | 4 | 3 |
| 예상 전체 구조질량 | 55-75 kg | 60-85 kg | 70-95 kg |
| 예상 제작비 | 3.2-4.0백만원, 확인 필요 | 3.8-4.8백만원, 확인 필요 | 3.6-4.8백만원, 확인 필요 |

## 3. 예산 배분 가이드 - 대안 A

아래 범위는 구매/가공 견적 전 계획값이다. 상한 견적을 모두 합하면 4백만원을 초과하므로 실제 발주 전 우선순위 조정이 필요하다.

| 항목 | 계획 범위 (천원) | 상태 |
|---|---:|---|
| 구조 프레임·판재 | 550-800 | 확인 필요 |
| 액추에이터/스크루잭 3축 | 850-1,200 | 확인 필요 |
| 조인트·가이드·베어링 | 250-400 | 확인 필요 |
| 카트 결합장치 | 150-300 | 확인 필요 |
| 센서·제어부품 | 350-550 | 확인 필요 |
| 전장함·배선 | 150-250 | 확인 필요 |
| 외주 가공 | 400-600 | 확인 필요 |
| 표면처리·마감 | 100-180 | 확인 필요 |
| 재가공·예비비 | 250-400 | 확인 필요 |
| **목표 총액** | **3,050-4,680** | **4,000 이내 조정 필요** |

비용 초과 시 안전 관련 조인트·스토퍼·래치·비상정지는 축소하지 않는다. 우선적으로 표면처리, 외장 커버, 고급 센서, 100 mm 대신 50 mm 초기 스트로크의 단계 구매를 검토한다.

## 4. 최종 추천

**대안 A: 3점 독립 리프팅 + 중앙 키드 텔레스코픽/카단 가이드**를 1차 PoC 개념으로 선정한다.

선정 이유는 단순히 액추에이터 수가 적기 때문이 아니다. 세 점이 하나의 상부 평면을 유일하게 결정해 4점의 비틀림 과구속을 피하고, 중앙 카단 가이드가 X/Y/Yaw를 명시적으로 구속하며, 분리형보다 낮은 적층 높이와 넓은 카트 결합 공간을 제공하기 때문이다.

권장 운용범위는 우선 Pitch/Roll 각각 ±3°, Lift 0-100 mm이다. ±5°는 약 215 mm 유효 스트로크와 8.5° 이상 조인트 굴절을 수용할 수 있을 때 확장한다. ±8°는 스트로크·높이·외곽 변위가 급증하므로 현 PoC에서는 권장하지 않는다.

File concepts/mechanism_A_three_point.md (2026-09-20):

# 대안 A - 3점 독립 리프팅 + 중앙 구속 가이드

## 1. 구성

권장 배치는 전방 중앙 1점과 후방 좌·우 2점의 삼각 지지이다.

- A1: `(X, Y) = (+300, 0) mm`
- A2: `(X, Y) = (-280, +250) mm`
- A3: `(X, Y) = (-280, -250) mm`
- 각 지지점: 위치 피드백이 있는 자가잠김 스크루/리니어 액추에이터, 양단 구면 또는 클레비스 조인트
- 중앙: 키드 텔레스코픽 수직 슬라이드 + 상단 2축 카단 조인트
- 상부: 볼트 조립식 프레임과 교체식 카트 인터페이스 판
- 하부: 교체식 범용 장착판

## 2. 자유도 구속 논리

중앙 키드 슬라이드는 중앙점의 X/Y 이동과 슬라이드 축 주위 Yaw를 막고 Z 이동만 허용한다. 슬라이드 상단 카단 조인트는 X/Y축 회전, 즉 Roll/Pitch를 허용하면서 토크를 전달하므로 Yaw를 계속 구속한다.

세 액추에이터의 양단 조인트는 상부판 기울기에 필요한 작은 각도 변화를 흡수하며, 액추에이터 로드가 X/Y/Yaw 구속 역할을 담당하지 않는다. 따라서 상부 허용 운동은 `Z + Pitch + Roll`의 3자유도이고 액추에이터 길이 3개가 이를 독립적으로 결정한다.

## 3. 개념 기구학

상부판의 목표 자세를 다음으로 둔다.

`T = [0, 0, d0 + h]`, `R = Ry(pitch) · Rx(roll)`, `d0 = 160 mm`

중립 상태에서 상·하부 조인트 X/Y 좌표가 동일할 때 액추에이터 길이는 다음과 같다.

`L_i = || T + R·p_i - b_i ||`

`h = 0, 50, 100 mm`, Pitch/Roll 각각 `-θ, 0, +θ`의 27개 조합을 계산한 결과는 다음과 같다. 값은 제품 수축 길이가 아니라 조인트 중심 간 길이이다.

| 각도 sweep | A1 길이 범위 | A2/A3 길이 범위 | 최대 기하학 스트로크 | 권장 유효 스트로크(끝단 여유 포함) |
|---|---:|---:|---:|---:|
| ±3° | 144.3-275.7 mm | 132.3-287.7 mm | 155.4 mm | ≥175 mm |
| ±5° | 133.9-286.1 mm | 113.9-306.1 mm | 192.2 mm | ≥215 mm |
| ±8° | 118.3-301.8 mm | 86.9-333.5 mm | 246.6 mm | ≥270 mm |

중립 길이는 `h = 50 mm`, Pitch=Roll=0°에서 210 mm이다. ±3°는 100 mm 리프트와 함께 구현할 때도 스트로크와 조인트 각도 측면에서 가장 현실적이다.

| 항목 | ±3° | ±5° | ±8° |
|---|---:|---:|---:|
| 액추에이터 축의 최대 수직 이탈각 | 0.5° | 1.6° | 5.2° |
| 상부 조인트 최대 굴절각 | 4.7° | 8.5° | 16.1° |
| 900×800 판 외곽 대각선 최고-최저 차 | 약 89 mm | 약 148 mm | 약 237 mm |
| 중앙 카단 합성 기울기 | 약 4.2° | 약 7.1° | 약 11.3° |

직동식이므로 링크 토글형 사점은 없다. 다만 나사잭의 자가잠김 여부, 하한에서의 내부 너트 충돌, 카단 조인트의 최대 굴절각은 실제 제품 데이터시트로 검증해야 한다.

## 4. 초기 반력 및 액추에이터 최소 사양

상부 이동질량 임시 범위는 40-90 kg이고 중량은 약 392-883 N이다.

- 중앙하중: 각 지지점 약 131-294 N
- X/Y 편심을 각각 150 mm까지 허용한 삼각지지 정역학: 최대 압축 반력 약 `0.741 W`, 최대 들림 반력 약 `0.171 W`
- 90 kg 조건: 최대 압축 약 654 N, 최대 인장 약 151 N
- 안전계수 2.0 적용 개념값: 압축 약 1.31 kN, 인장 약 0.30 kN

따라서 Phase 2 제품 탐색의 출발점은 액추에이터당 **동적 추력 1.5 kN 이상, 정적 유지하중 2.0 kN 이상, 양방향 하중을 전달하는 기계식 연결**이다. 이는 최종 선정값이 아니며 실제 구조질량, 자재 편심, 속도, 충격, 듀티사이클을 반영해 재계산해야 한다.

## 5. 예상 외형과 제작성

| 상태 | 플랫폼 중앙 상면 높이 추정 |
|---|---:|
| 수축/리프트 0 | 270 ±15 mm |
| 중립/리프트 50 | 320 ±15 mm |
| 완전 상승/리프트 100 | 370 ±15 mm |

250 mm 목표보다 약 20 mm 이상 높아질 가능성이 있다. 175 mm급 유효 이동, 양단 조인트, 중앙 가이드, 스토퍼의 적층을 250 mm 안에 넣을 수 있는지는 액추에이터 외형 확인 전 확정할 수 없다.

제작안은 30/40계열 프로파일 내부 프레임, 절곡 강판 액추에이터 브래킷, 가공된 중앙 가이드 하우징, 볼트 조립식 상·하부 판을 우선한다. 주요 하중 브래킷은 금속으로 제작한다.

## 6. 장점

- 세 점은 하나의 평면을 유일하게 정하므로 4점 방식보다 비틀림/걸림 위험이 작다.
- 같은 액추에이터 3개로 Lift, Pitch, Roll을 구현한다.
- 중앙 카단 가이드가 허용/구속 자유도를 명확히 분리한다.
- 카트 결합장치를 위한 상부 공간이 비교적 넓다.
- 볼트 조립과 지지점 좌표 변경이 쉬워 PoC 수정성이 높다.

## 7. 위험과 완화책

| 위험 | 영향 | 완화 개념 |
|---|---|---|
| 삼각 지지영역 밖의 하중중심 | 한 액추에이터 인장/들림 | 양방향 조인트, 카트 래치, 허용 CG 영역 정의 |
| 중앙 가이드 과구속 또는 카단 걸림 | 운동 정지, 횡하중 | 카단 정렬, 조립 슬롯, 각도 스토퍼, 저속 홈 테스트 |
| 250 mm 높이 초과 | 하부 이동체 간섭 | 단축형 액추에이터/스크루잭 비교, 50 mm 리프트 옵션, 높이 승인 |
| 액추에이터 위치 오차 | 기울기 오차 | 절대/증분 위치 피드백, 소프트 동기화, 기계식 하한 기준잡기 |
| 전원 차단 급강하 | 카트 낙하 위험 | 자가잠김/브레이크, 독립 스토퍼, 비상정지 |
| 손 끼임·케이블 끼임 | 부상/고장 | 측면 가드, 벨로즈, 서비스 루프, 체결 인터록 |

## 8. 판정

Phase 1의 권장 구조이다. 1차 PoC는 Pitch/Roll 각각 ±3°, 100 mm 리프트를 기준으로 하고 ±5°는 액추에이터 패키징 확인 후 확장 옵션으로 남긴다.

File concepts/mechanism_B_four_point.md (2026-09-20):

# 대안 B - 4점 독립 리프팅

## 1. 구성

- 액추에이터 좌표: `(±300, ±250) mm`
- 네 모서리 근처의 독립 스크루/리니어 액추에이터
- 양단 구면조인트 또는 한 점 이상의 컴플라이언트 연결
- 상부판 X/Y/Yaw 구속용 중앙 또는 측면 가이드
- 네 축 위치 피드백과 동기 제어

## 2. 기구학 결과

대안 A와 동일한 `d0 = 160 mm`, 0/50/100 mm 리프트 및 Pitch/Roll 조합을 사용했다.

| 각도 sweep | 액추에이터별 길이 범위 | 최대 기하학 스트로크 | 권장 유효 스트로크 |
|---|---:|---:|---:|
| ±3° | 131.2-288.8 mm | 157.5 mm | ≥180 mm |
| ±5° | 112.2-307.9 mm | 195.7 mm | ≥220 mm |
| ±8° | 84.2-336.3 mm | 252.1 mm | ≥280 mm |

기하학 스트로크는 3점 방식과 유사하지만 네 액추에이터 길이는 상부판의 3자유도보다 하나 많은 구속조건을 만든다. 실제 프레임과 조인트가 완전 강체이면 네 길이 명령이 한 평면과 일치하지 않는 순간 비틀림 내력이 발생한다.

## 3. 하중과 제어

이상적인 동일 강성 조건에서 중앙하중은 각 액추에이터가 `W/4`를 지지한다. X/Y 각각 150 mm 편심을 단순 선형 분담하면 가장 큰 코너가 약 `0.60 W`를 부담할 수 있다. 그러나 실제 반력은 프레임 강성, 설치 높이, 나사 백래시, 센서 영점에 크게 좌우된다.

제어기는 네 위치를 단순히 같은 값으로 명령해서는 안 된다. 목표 평면으로부터 각 축 길이를 산출하고, 한 축을 컴플라이언트/로드셀 감시 축으로 두거나 상부 연결 중 한 곳에 수직 플로팅 조인트를 적용해야 한다.

## 4. 예상 외형

| 상태 | 플랫폼 중앙 상면 높이 추정 |
|---|---:|
| 수축 | 285 ±15 mm |
| 중립 50 mm | 335 ±15 mm |
| 완전 상승 100 mm | 385 ±15 mm |

코너 브래킷과 가드 네 세트가 카트 결합부 및 외장 공간을 줄인다. 예상 전체 구조질량은 60-85 kg 범위이다.

## 5. 장점

- 직관적인 대칭 배치와 넓은 지지영역
- 중앙하중에서 액추에이터 1개당 정적 반력이 작음
- 네 모서리의 변위를 직접 계측할 수 있음
- 상부판의 국부 처짐을 줄일 가능성

## 6. 위험

- 4점 과구속으로 프레임 비틀림, 걸림, 액추에이터 과전류가 발생할 수 있음
- 센서 영점과 피치 오차 누적으로 한 축에 하중이 집중될 수 있음
- 액추에이터·드라이버·배선·리미트가 4세트로 증가
- 조립 공차와 유지보수 부담이 증가
- 액추에이터 고장 시 대각 비틀림이 큼
- 중앙 가이드를 추가하면 과구속 문제가 더 커질 수 있음

## 7. 판정

넓은 지지영역은 장점이지만 PoC에서 강성/동기 제어 문제를 동시에 해결해야 한다. 컴플라이언트 네 번째 지지 또는 하중 균등화 장치가 없는 순수 4점 독립 방식은 권장하지 않는다.

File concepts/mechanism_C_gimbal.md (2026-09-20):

# 대안 C - 리프트와 2축 보정 분리형

## 1. 구성

세 운동을 서로 다른 단계로 분리한다.

1. 하부 Z 리프트: 직접 리프트 컬럼 또는 저상형 가이드 리프트
2. 중간 Pitch 프레임: Y축 피벗과 1개 틸트 액추에이터
3. 상부 Roll 프레임: X축 피벗과 1개 틸트 액추에이터
4. 최상단 카트 결합판

각 축이 베어링과 피벗으로 명확히 정의되므로 X/Y/Yaw 구속이 쉽다.

## 2. 개념 기구학

Pitch 유효 반경 300 mm, Roll 유효 반경 250 mm에서 피벗 반대편의 직접 높이차를 틸트 액추에이터 이동량의 1차 근사로 사용했다. 실제 링크 설치각에 따라 더 큰 스트로크와 추력이 필요하다.

| 각도 sweep | Pitch 틸트 전범위 이동 | Roll 틸트 전범위 이동 | Z 리프트 |
|---|---:|---:|---:|
| ±3° | 약 31.4 mm | 약 26.2 mm | 100 mm |
| ±5° | 약 52.3 mm | 약 43.6 mm | 100 mm |
| ±8° | 약 83.5 mm | 약 69.6 mm | 100 mm |

틸트 액추에이터는 피벗과 작용선이 일치하는 사점에 접근하지 않도록 수평·수직 오프셋을 둬야 한다. 가위형 Z 리프트를 사용할 경우 완전 수축에서 사점과 큰 입력력이 발생할 수 있으므로, Phase 2에서는 가이드된 직접 스크루 리프트를 우선 비교한다.

## 3. 예상 외형

| 상태 | 플랫폼 중앙 상면 높이 추정 |
|---|---:|
| 수축 | 325 ±20 mm |
| 중립 50 mm | 375 ±20 mm |
| 완전 상승 100 mm | 425 ±20 mm |

세 프레임, 두 피벗 베어링 세트, Z 가이드가 적층되어 250 mm 목표를 가장 크게 초과한다. 예상 전체 구조질량은 70-95 kg 범위이다.

## 4. 장점

- Lift, Pitch, Roll 제어가 기계적으로 분리되어 제어식과 고장진단이 단순함
- 피벗이 자유도를 명확히 정의해 과구속 위험이 낮음
- 각 축의 독립 기계식 스토퍼 설치가 쉬움
- 틸트 액추에이터 스트로크가 3/4점 방식보다 짧음

## 5. 위험

- 수축 높이와 구조질량이 가장 큼
- 적층 프레임의 모멘트암 증가로 피벗·베어링 하중이 큼
- 부품 수, 조립 공차, 비용 증가
- 가장 위의 Roll 프레임과 카트 결합부 사이 공간이 제한됨
- 가위 리프트 사용 시 저상 사점, 손 끼임, 큰 구동력 문제가 있음
- 회전축 순서에 따라 카트 인터페이스 위치와 케이블 경로가 달라짐

## 6. 판정

제어와 구속의 명확성은 우수하지만 250 mm 목표, 예산, 수정 용이성 측면에서 1차 PoC에 불리하다. 높이 제한이 완화되고 정밀 각도 제어가 우선일 때의 백업안으로 유지한다.

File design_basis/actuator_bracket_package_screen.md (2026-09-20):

# JNT-BR-01 HRT8E actuator bracket package

Status: Phase 2 detailed CAD seed updated 2026-08-27. Not approved for fabrication.

## Purpose

The HRT8E-style M8 rod end remains the leading simple actuator-end candidate for the user-confirmed +/-3 degree PoC. JNT-BR-01 keeps the actuator force and pin axis intersecting at the spherical-bearing center, so the threaded shank is not used as a bending spacer.

The package is now represented by preliminary detailed CAD with boxed double-shear lugs, replaceable bushings, misalignment-spacer envelopes and retained shoulder-pin hardware. It is not a fabrication drawing or purchased-bracket release.

## Official HRT8E inputs

MinebeaMitsumi data was rechecked on 2026-08-27: 8 mm bore, 23 mm body diameter, 11 mm eye width, 8.25 mm center height, 46 mm center-to-end, M8x1.25 thread, 29 mm thread length and 14 deg articulation. The actuator-axis screen continues to use the lower 5.29 kN axial static value instead of the 26.77 kN radial value.

## Coordinate system and load path

Set the spherical-bearing center as `J`.

```text
+X: neutral actuator force line toward the actuator
+Y: through-pin axis
+Z: completes the right-hand frame
```

The actuator resultant and pin axis must intersect at `J`. The M8 threaded shank provides thread engagement to the actuator-side adapter only.

## Active detailed seed

| Item | Preliminary seed | Rule |
|---|---|---|
| Bracket form | Two symmetric 8 mm steel lugs tied into a boxed base yoke | Do not use a single thin lug as the primary pin support. |
| Pin | 8 mm shoulder-pin envelope in double shear | Exact pin grade, shoulder length and positive retention remain open. |
| Loaded pin support span | 18 mm between lug inner faces | Revised from 16 mm after applying the official eye envelope. Recalculate if the real stack is wider. |
| Lug section | 8 mm thickness, at least 32 mm load width, no more than 30 mm free root-length seed | Final edge distance, outline and joining detail remain open. |
| Lug bushings | 12 mm OD x 8.2 mm ID x 8 mm replaceable envelopes | Final fit, material and retention remain open. |
| Misalignment spacers | 3.5 mm per side, 10.8 mm OD envelope | Exact purchased or turned detail remains open. |
| Bracket attachment | Four M8 clearance-hole envelopes per boxed yoke | Final backing plate, joint method, torque and edge distances remain open. |
| Articulation | No contact through the full 14 deg catalogue envelope | Numerical projection is not a substitute for V-01. |
| Fallback | RBLD8-style high-angle link-ball package | Use only if the physical HRT8E package fails. |

## Clearance revision

The earlier 16 mm gap was too tight once the official body dimensions were used. A conservative flat-lug projection gives:

```text
projected width = 11*cos(14 deg) + 23*sin(14 deg)
                = about 16.24 mm
```

The active 18 mm gap leaves about 1.76 mm total numerical clearance, or about 0.88 mm per side. Chamfers, real spherical insert geometry, spacer shape and tolerances are not fully represented, so physical proof remains mandatory.

## Active low-load screen

| Check | Candidate result | Interpretation |
|---|---:|---|
| Required articulation | about 12.94 deg | About 1.06 deg remains against the 14 deg catalogue value. |
| Pin double shear | about 8.7 MPa | Below the 100 MPa placeholder comparison. |
| Pin bending | about 78.5 MPa | 8 mm pin with 18 mm support span; below the 150 MPa placeholder comparison. |
| Lug bearing | about 13.7 MPa | Below the 100 MPa placeholder comparison. |
| Lug-root bending | about 38.5 MPa | Below the 150 MPa placeholder comparison. |
| 14 deg projected eye clearance | about 1.76 mm total | Numerical envelope only. |

These comparisons do not establish material grade, weld capacity, fatigue life, shock resistance, thread engagement, fits or final pin retention.

## Rejected load paths

- Single-shear primary lug.
- Any threaded-shank standoff that puts a bending moment into the M8 root.
- A bracket that contacts the rod-end body before full required articulation.
- A pin support span wider than 18 mm without a new calculation.

## V-01 physical acceptance

1. Confirm official dimensions against the physical HRT8E.
2. Record the real spacer, shoulder-pin, retainer and actuator-thread adapter stack.
3. Make a low-cost gauge from the detailed CAD seed.
4. Sweep 14 deg in both principal planes and the diagonal combination with no contact.
5. Measure the support span and recalculate if it exceeds 18 mm.
6. Confirm retention hardware cannot rub the moving rod end.

Open items are the actuator-thread adapter, exact spacer and pin hardware, bushing fit, lug material and joining, bracket attachment, edge distances, fatigue/shock validation and the physical V-01 sweep.

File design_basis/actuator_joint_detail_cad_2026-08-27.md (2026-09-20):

# RADIAL_3_CLEAN actuator joint detail CAD

Date: 2026-08-27

Status: Phase 2 preliminary detailed CAD seed. Not approved for fabrication.

## Decision

Keep the three equal 120-degree radial actuators and replace the blocky placeholder clevises with six serviceable `JNT-BR-01-HRT8E` packages. Each package uses a centered double-shear load path, replaceable lug bushings, compact misalignment spacers and retained M8 pin hardware.

## Official HRT8E inputs

MinebeaMitsumi official data was rechecked on 2026-08-27:

- bore: 8 mm
- body diameter: 23 mm
- eye width: 11 mm
- center height: 8.25 mm
- center-to-end: 46 mm
- thread: M8x1.25
- thread length: 29 mm
- allowable articulation: 14 deg
- axial static limit: 5.29 kN

Source: https://product.minebeamitsumi.com/en/product/category/bearing/rodend/standard/parts/HRTE.html

## Geometry revision

The earlier 16 mm inner-gap seed was retained before the official body dimensions were applied. A conservative flat-lug projection gives about 16.24 mm at 14 deg. Therefore 16 mm cannot conservatively clear the catalogue angle. The active preliminary gap is 18 mm, leaving about 1.76 mm total numerical clearance.

Physical two-plane and diagonal motion still must be checked because the real spherical insert, chamfers, spacer shape and manufacturing variation are not represented completely.

## Active CAD seed

| Item | Preliminary value |
|---|---:|
| Lug thickness | 8 mm |
| Inner gap / pin support span | 18 mm |
| Lug bushing envelope | 12 mm OD x 8.2 mm ID x 8 mm |
| Misalignment spacer envelope | 3.5 mm wide x 10.8 mm OD, two per joint |
| Pin | 8 mm shoulder-pin envelope |
| Pin retention | head + washer + locking-retainer envelope |
| Mounting | four 8.5 mm clearance holes per boxed yoke |

At the regenerated low-load screen, pin double shear is about 8.7 MPa, pin bending about 78.5 MPa, lug bearing about 13.7 MPa and lug-root bending about 38.5 MPa. These are placeholder comparisons, not certified allowables.

## CAD outputs

- `outputs/cad/step/radial_actuator_joint_packages_neutral.step`
- `outputs/renders/phase2_actuator_joint_detail.png`
- Full assembly STEP states under `outputs/cad/step/`

## Still open

- Actual HRT8E purchase and dimensional inspection
- Female-threaded adapter from the selected actuator end to HRT8E M8x1.25
- Exact shoulder bolt or clevis pin grade, shoulder length and lock method
- Bushing material, fit, lubrication and replacement retention
- Bracket material, joining method, backing plate, bolt grade and torque
- 14 deg two-plane and diagonal physical sweep with no contact
- Fatigue, shock, impact and wear validation

V-01 remains open until measured physical evidence is stored in `logs/`.

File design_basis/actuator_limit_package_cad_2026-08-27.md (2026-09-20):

# LS-01M static-bench actuator-axis mechanical-stop CAD seed

Status: `PHASE_2_PRELIMINARY_NOT_FOR_FABRICATION`

## Purpose

LS-01M is the reduced stationary-bench version of the earlier LS-01 stop/limit cassette. It preserves the active `RADIAL_3_CLEAN` arrangement while removing the external D4N switch, trip-cam and slotted-bracket hardware from the active CAD and BOM.

Each actuator receives:

- one MB21-derived fixed carrier located on the official body-bracket datum,
- two 12 mm moving rods on 104 mm centers,
- one keyed capture crosshead connected to the front-clevis adapter without clamping the chrome rod,
- two mechanical collars per travel direction,
- two replaceable guide bushings.

The electrical travel boundary is the actuator's built-in non-adjustable end-limit path. The external D4N/cam package remains archived research, not an active build item.

## Coordinate conversion

Let `L` be actuator lower-pin to upper-pin length, `s_f = 220 mm` the fixed carrier station from the lower pin, and `o_c = 0 mm` the moving datum at the front-clevis pin centre. A collar or cam at distance `d` behind the crosshead reaches the fixed carrier when:

```text
d = L_contact - o_c - s_f
```

| Event | Actuator length | Offset behind crosshead |
|---|---:|---:|
| Lower mechanical stop | 324 mm | 104 mm |
| Lower commanded boundary | 334 mm | control value only |
| Upper commanded boundary | 508 mm | control value only |
| Upper mechanical stop | 518 mm | 298 mm |

The command boundaries remain inside the mechanical contacts. The actuator's built-in end limits are not adjustable and their actual trip positions must be measured on all three purchased units.

## Geometry seed

| Parameter | Value |
|---|---:|
| Moving rods | 2 x 12 mm diameter x 320 mm |
| Rod center spacing | 104 mm |
| Fixed carrier station | 220 mm from lower pin |
| Moving datum | upper/front clevis pin centre |
| Capture bridge setback | 32 mm behind front pin |
| MB21 official STEP envelope | 50 x 82.854 x 100 mm |
| Guide bushings | 16 mm OD x 12.4 mm bore x 14 mm |
| Mechanical collar envelope | 12 mm bore x 28 mm OD x 11 mm width |

The rod spacing was initially 86 mm. CAD intersection checks found that the 28 mm stop collars and then-active 20 mm trip cams entered the simplified motor-box envelope. Increasing the centers to 104 mm and the carrier width to 132 mm removed those intersections. The D4N/cam hardware was later removed for the stationary-bench variant, but the wider twin-rod layout is retained for collar and carrier clearance.

The earlier 42 mm moving-crosshead station was discarded after separating the official actuator STEP into fixed-body, moving-rod/clevis, and moving-shoulder solids. It did not provide a defensible clevis attachment datum. Moving the datum to the front pin changed the four offsets to 104/109/293/298 mm and required 320 mm rods. A first annular capture entered the upper yoke by 49.57 mm3, so it was removed in favor of two keyed capture straps and a relieved bridge. A 28 mm bridge setback still left 0.99 mm3 at combined pitch/roll; 32 mm clears all named poses in the current preliminary envelopes.

The MB21 bracket spans 170 to 270 mm from the rear pin when centered at 220 mm. The source STEP fixed-body zone is approximately 45.17 to 288.73 mm from the rear pin, leaving about 18.73 mm at the tighter end. These are STEP-derived layout measurements, not toleranced dimensions or proof that MB21 may carry impact stop reaction.

## Static reference

The retained stop reference is 42 kg lifted mass with a 2.0 static factor:

```text
F_package = 42 kg x 9.80665 m/s^2 x 2.0 = 823.8 N
F_equal-share per rod = 411.9 N
12 mm rod axial stress = 3.64 MPa
collar-face average contact pressure = 0.82 MPa
```

For procurement screening, each collar must have verified axial holding or measured push-off of at least 823.8 N, twice the equal-share rod reaction. This target does not approve impact capacity. One-rod load concentration, crosshead bending, carrier attachment, actuator-housing load acceptance, fatigue, contamination, and a falling load remain unresolved.

## Purchased-part reference

- [Ruland MSP-12-FZ official page](https://www.ruland.com/msp-12-fz.html): 12 mm bore, 28 mm OD, 11 mm width, two-piece steel collar, two M4 x 12 screws and 4.6 Nm seating torque. Project-specific push-off and impact acceptance are not published on the referenced page.

The former Omron D4N-4D32 research is retained in the source register only. It is not procured for `LS-01M_STATIC_BENCH_MINIMAL`.

## Required physical validation

1. Ask Firgelli whether MB21 and the actuator housing may carry the calculated external stop reaction and impact. If not, replace it with a lower-yoke-mounted fixed frame.
2. Build and sweep one JNT-CG-01 factory-eye cradle and keyed crosshead; confirm it never clamps or side-loads the chrome rod.
3. Measure actual pin-to-pin endpoints and internal-limit positions for all three purchased actuators.
4. Apply a controlled static push-off test to each collar above 823.8 N, then perform low-speed end tests with no person under or on the platform.
5. Replicate the cassette only after one complete actuator module passes the fit and motion check.

No part of this package is approved for fabrication, certification, or carrying people.

See `design_basis/firgelli_mount_datum_review_2026-08-27.md` for the archived STEP hashes and datum decision.

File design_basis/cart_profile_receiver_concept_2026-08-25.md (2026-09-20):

# Aluminum Profile Cart Receiver Concept

Date: 2026-08-25

Status: user preference recorded. Phase 1 preliminary concept only; not approved for fabrication.

Layout screen: `design_basis/cart_profile_receiver_layout_screen.md`

Hardpoint screen: `design_basis/cart_receiver_hardpoint_screen.md`

## Scope

This note defines only the mechanical receiver/interface zones for coupling the leveling device to a new cart lower frame.

It does not design the cart body, wheels, casters, drive system, navigation system, AMR/AGV base, or payload rack.

## User Decision

The user chose an aluminum profile frame direction for the cart-side receiver/interface.

Interpretation for Phase 1:

- Use bolt-together aluminum T-slot/profile members as the adjustable receiver frame.
- Keep welding to a minimum.
- Keep profile slot adjustment available during mock-up alignment.
- Do not rely on the aluminum profile slot faces themselves as the final locating, wear, or shear surfaces.
- Use local metal insert plates, bushings, rest pads, latch keepers, or dowel plates wherever repeated seating or concentrated contact occurs.

## Recommended Preliminary Architecture

The current preferred receiver structure is:

```text
new cart lower frame
  -> aluminum profile receiver rails / rectangular subframe
  -> bolted local steel or aluminum hard-point plates
  -> rest pads + one master locator + one slotted/diamond secondary locator
  -> mechanical latches with secondary lock and latch-closed sensing
  -> leveling device lower interface
```

Recommended layout principles:

| Item | Preliminary direction | Why |
|---|---|---|
| Receiver structure | Bolt-together aluminum profile rails or shallow subframe | Easy fabrication, adjustment, and rework |
| Profile class | 30 mm or 40 mm class T-slot/profile; exact section TBD | 30 mm helps the 10 kg cart target; 40 mm helps local stiffness and compatibility |
| Local hard points | Separate insert plates for pins, rest pads, latch keepers, and stop blocks | Avoids fretting or wear on raw profile slots |
| Primary locator | One round/tapered master locator | Defines repeatable X/Y seating |
| Secondary locator | One slotted or diamond locator | Adds yaw control while avoiding overconstraint |
| Rest support | Four shim-adjustable rest pads near the receiver corners or load paths | Carries vertical seating load without using latch hooks as supports |
| Latches | 2 minimum, 4 still acceptable as a placeholder for symmetric preload | Latches retain/preload; they do not carry primary horizontal shear |
| Adjustment | Slot adjustment for mock-up, then fixed with dowels, clamp plates, or keyed plates after alignment | Prevents the final interface from depending only on friction |

The current layout candidate carried forward from the first screen is `CR-01`: two 760 mm HFS8-4040 longitudinal receiver rails inside a 760 mm x 560 mm receiver zone. The current hardpoint seed is `CR-01-H1`.

## Candidate Parameter Seeds

These are layout seeds for the next Phase 1 review. They are not manufacturing dimensions.

| Parameter | Candidate seed | Status |
|---|---:|---|
| Device footprint reference | 900 mm L x 800 mm W | Existing target, not image-derived |
| Disconnected device height envelope | 250 to 300 mm | User confirmed |
| Receiver rail direction | Prefer two longitudinal rails along the 900 mm direction | Provisional |
| Receiver rail span | Keep as a parameter inside the 800 mm width envelope | Open |
| Locator span | Maximize practical X/Y separation inside the receiver envelope | Open |
| Rest pad count | 4 | Provisional |
| Latch count | 2 minimum; 4 placeholder for current low-load screen | Open |
| Latch function | Preload/uplift/retention only | Fixed principle |
| Horizontal shear path | Locators, rest geometry, and receiver hard points | Fixed principle |
| Aluminum profile role | Adjustable frame/backbone | User preferred |
| Steel or hard insert role | Local contact, wear, pin bearing, latch keeper, stop face | Provisional hard rule |

## Low-Load Screen Link

The current user-confirmed low-load screen remains the sizing reference:

| Screen item | Current value |
|---|---:|
| Lifted mass baseline | 42 kg |
| Actuator force baseline | about 618 N |
| Active interface vertical design load | about 618 N |
| Active worst interface moment | about 108 Nm |
| Active guide-pin shear design load | about 154 N |
| Active total latch uplift design load | about 124 N |
| Active per-latch uplift with 4 latches | about 31 N |
| YAW-A design yaw torque | about 16 Nm |

These values are low enough that the main receiver risks are not bulk profile strength. The main risks are joint slip, local bearing/wear, backlash, latch geometry, profile connector stiffness, and tolerance stack-up.

## Practical Risks To Carry Forward

- A full 40 x 40 profile cart frame can consume the 10 kg cart mass budget quickly; use 40 mm class members only where they are useful.
- Profile slot friction alone should not be trusted as the final anti-slip or yaw reference after repeated coupling.
- Locating pins should seat into replaceable or well-supported inserts, not directly into soft slot edges.
- Rest pad heights should be shim-adjustable so the cart does not rock on three accidental high points.
- Latch handles and release directions must stay outside the actuator, central guide, and pinch-zone envelope.
- Final profile section, connector type, fastener size, and bracket plate thickness still need source-backed selection before `APPROVE PARAMETERS`.

## Next Work

1. Convert this concept into a parametric receiver-zone sketch using variables, not fabrication drawings.
2. Choose whether the cart-side receiver uses 30 mm class profile generally with 40 mm local rails, or one consistent 40 mm profile family.
3. Recalculate latch/locator loads after choosing locator span and latch positions.
4. Keep the cart mass estimate close to 10 kg by separating the receiver hardware mass from any future cart body mass.

```text
ALUMINUM PROFILE RECEIVER DIRECTION RECORDED
PHASE 1 PRELIMINARY ONLY
NOT APPROVED FOR FABRICATION
```

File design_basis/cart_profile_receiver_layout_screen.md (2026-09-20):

# Cart Profile Receiver Layout Screen

Date: 2026-08-25

Status: Phase 1 preliminary layout screen only. Not approved for fabrication.

Related concept note: `design_basis/cart_profile_receiver_concept_2026-08-25.md`

Calculation: `calculations/cart_profile_receiver_screen.py`

Hardpoint follow-up: `design_basis/cart_receiver_hardpoint_screen.md`

## Coordinate Basis

Use the same project coordinate convention:

| Axis | Meaning |
|---|---|
| X | device length direction, nominal 900 mm envelope |
| Y | device width direction, nominal 800 mm envelope |
| Z | vertical |

Origin is the nominal device center. No cart dimension is inferred from images.

## Preferred Preliminary Receiver Zone

The current preferred cart-side receiver zone is a light two-rail kit, not a full cart frame:

| Item | Candidate seed |
|---|---:|
| Receiver outer length | 760 mm |
| Receiver outer width | 560 mm |
| Longitudinal rail count | 2 |
| Longitudinal rail length | 760 mm each |
| Rail centerline Y positions | +/-260 mm |
| Rest pad X span | 620 mm |
| Rest pad Y span | 520 mm |
| Locator X span | 520 mm |
| Master locator seed | X -260 mm, Y 0 mm |
| Slotted/diamond secondary locator seed | X +260 mm, Y 0 mm |
| Latch placeholder count | 4 |
| Latch seed positions | +/-330 mm X, +/-260 mm Y |

Interpretation:

- Two longitudinal aluminum-profile receiver rails are the preferred backbone.
- Cross support belongs to the new cart lower frame and is not designed here.
- Local hard points are bolted to the rails or adjacent cart-frame members.
- The positions above are receiver-zone seeds, not hole coordinates.

## Mass Screen

The hard-point allowance is a placeholder containing rest blocks, locator plates, latch keepers, stop tabs, and fasteners. It is not a BOM.

| Layout | Profile basis | Profile length | Profile mass | Hard-point allowance | Total receiver mass | Status |
|---|---|---:|---:|---:|---:|---|
| Two-rail receiver kit | HFS8-4040 | 1.52 m | 2.63 kg | 1.87 kg | 4.50 kg | Preferred |
| Self-contained rectangular receiver | HFS8-4040 | 2.64 m | 4.57 kg | 1.87 kg | 6.43 kg | Heavier reserve |
| Two-rail stiff reserve | GFS8-4040 | 1.52 m | 3.30 kg | 1.87 kg | 5.16 kg | Stiffness reserve |
| Self-contained stiff rectangular reserve | GFS8-4040 | 2.64 m | 5.73 kg | 1.87 kg | 7.60 kg | Reject for 10 kg cart target unless mass target changes |

Current reading:

- The two-rail HFS8-4040 receiver kit uses about 45% of the 10 kg empty-cart basis.
- A self-contained rectangular subframe can work structurally, but it consumes too much of the 10 kg cart mass budget for a simple PoC.
- If 40 mm profile feels too heavy after the full cart frame is sketched, a 30 mm profile family may be studied, but it needs its own source-backed mass/stiffness data before parameter approval.

## Rest Pad Screen

Using the active low-load worst interface moment from `calculations/interface_moments.py`:

| Item | Value |
|---|---:|
| Vertical design load | about 824 N |
| Worst roll moment in active screen | about 108 Nm |
| Rest pad X span | 620 mm |
| Rest pad Y span | 520 mm |
| Base load per pad | about 206 N |
| Maximum screened pad load | about 331 N |
| Minimum screened pad load | about 81 N |

All four pads remain in compression in this simplified active screen. Shim adjustment is still required because profile assembly tolerances can otherwise leave one pad unloaded.

## Locator And Latch Screen

Using the current low-load latch and yaw screens:

| Item | Value |
|---|---:|
| Guide/locator shear design load | about 154 N |
| Master locator single-point shear if it carries all horizontal shear | about 154 N |
| Shared shear if two locators share load | about 77 N each |
| YAW-A design yaw torque reference | about 16 Nm |
| Yaw couple force at 520 mm locator span | about 32 N |
| Total latch uplift design load | about 124 N |
| Per-latch uplift with 4 latches | about 31 N |

The latch remains a retention and preload item only. The receiver geometry, locators, rest pads, and local stop faces should carry horizontal shear and repeatable alignment.

## Current Recommendation

Carry forward the following candidate:

```text
CR-01: two longitudinal HFS8-4040 receiver rails,
760 mm long, 560 mm receiver-zone width,
master locator + slotted/diamond secondary locator,
four shim-adjustable rest pads,
two minimum / four placeholder mechanical latches,
local metal hard points for all concentrated contact.
```

Carry as reserves:

- `CR-02`: self-contained HFS8 rectangular subframe if the cart frame cannot provide cross support.
- `CR-03`: GFS8 two-rail reserve if the HFS8 rail connector stiffness fails.
- `CR-04`: 30 mm-class profile study if the final cart mass exceeds the 10 kg target. This requires new source-backed profile data.

## Open Items Before Parameter Approval

- Exact profile family and local procurement code.
- Connector style, slot nut type, and CR-01-H1 dowel/keyed plate/positive stop details after alignment.
- Insert plate material and thickness.
- Locator hardware size and seating geometry.
- Rest pad thread, shim, or eccentric adjustment method.
- Latch keeper geometry, release clearance, secondary lock, and latch-closed sensing.
- Confirmation that the full cart including receiver stays near the 10 kg empty-cart target.

```text
CR-01 RECEIVER LAYOUT CANDIDATE DEFINED
PHASE 1 PRELIMINARY ONLY
NOT APPROVED FOR FABRICATION
```

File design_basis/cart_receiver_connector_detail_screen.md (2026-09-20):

# CR-01-H3 cart receiver connector detail / access screen

Status: Phase 1 preliminary screen. Not approved for fabrication.

## Purpose

CR-01-H2 selected the preferred connector topology: slot fasteners for adjustment and clamp, plus a shoulder/key/positive stop for final locating. CR-01-H3 maps that topology to each hard point so the next designer does not accidentally overconstrain the cart receiver.

This is still not a fabrication drawing. It is a connector-stack and bench-check rule set.

## Hardpoint-specific stack

| Code | Hard point | Role | Constrain | Release | Preliminary stack |
|---|---|---|---|---|---|
| CR-01-H3-L1 | Master locator | Repeatable X/Y location and horizontal shear | X, Y | - | Two M8-class T-slot fasteners plus shoulder/key positive stop; optional dowel after alignment |
| CR-01-H3-L2 | Slotted secondary locator | Yaw reference through separated Y reaction | Y | X | Two M8-class T-slot fasteners plus one-direction shoulder/key stop; do not pin both axes |
| CR-01-H3-RP | Rest pad | Z seating and height trimming | Z | X, Y | T-slot clamp plus accessible shim stack and lock feature |
| CR-01-H3-LK | Latch keeper | Preload/uplift retention and latch-closed sensing | Z uplift retention | primary horizontal shear | T-slot clamp plus local steel keeper; secondary lock and sensor reserve |

## Local bearing and access screen

| Screen | Result | Interpretation |
|---|---:|---|
| Profile wall / stop backing bearing with 3x local load factor | about 1.74 MPa | Low versus the placeholder 30 MPa aluminum bearing screen, but exact profile lip geometry is unresolved |
| Slot nut local clamp pressure with assumed 18 x 12 mm contact | about 18.5 MPa | Passes placeholder screen, but exact slot nut contact and torque are still not approved |
| Minimum tool access clearance seed | 25 mm | Keep shim, latch, and sensor hardware serviceable |
| Sensor envelope reserve seed | 25 x 25 x 35 mm | Placeholder for cart-present and latch-closed sensing only |

## Mock-up acceptance rules

Run at least 30 latch/unlatch/seating cycles before freezing the receiver connector stack.

Add a backing plate or stiffer local stack if any of these occur:

- Hard-point shift exceeds 0.2 mm.
- Fastener torque relaxation exceeds 20%.
- Profile wall marking or indentation appears.
- Latch preload visibly changes after cycling.

Add a dowel only after alignment is finalized and repeatability is more important than slot adjustability.

Reject any detail that:

- Makes the slotted secondary locator block both X and Y.
- Lets the latch hook carry primary horizontal shear.
- Uses an electrical sensor as a mechanical stop.

## Current carry-forward decision

```text
CR-01-H3
master locator fixed in X/Y
secondary locator constrains Y only and releases X
rest pads carry Z seating only
latch keepers carry preload/uplift only
backing plates are conditional after mock-up evidence
```

Before `APPROVE PARAMETERS`, the exact slot nut family, backing plate geometry, stop block shape, dowel position, latch/sensor access, and profile wall bearing detail remain open.

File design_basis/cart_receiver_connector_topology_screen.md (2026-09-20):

# CR-01-H2 cart receiver connector / positive-stop topology screen

Status: Phase 1 preliminary screen. Not approved for fabrication.

## Purpose

CR-01 and CR-01-H1 define the aluminum-profile receiver rails and local hard points. CR-01-H2 adds the next missing layer: how those hard points should be connected to the profile so that mock-up adjustment is easy, but final locating does not rely on profile-slot friction.

The controlling rule is:

```text
T-slot fasteners may clamp and adjust the hard point.
The final repeatable X/Y/yaw locating path needs a mechanical shoulder, key, dowel, or positive stop.
```

## Basis

- Active low-load baseline: 10 kg payload, about 10 kg empty cart, 22 kg moving structure.
- Receiver demand inherited from CR-01-H1: locator shear plus low-load yaw couple force.
- Calculated connector demand: about 186 N.
- Friction-only slip margin with the placeholder clamp assumption: about 6.45x.

This means bulk strength is not the current blocker. Repeatability, slot creep/slip, assembly adjustment, and avoiding a hidden final friction-only load path are the blockers.

## Candidate topology screen

| Code | Topology | Decision | Reason |
|---|---|---|---|
| CR-01-H2-A | Slot friction only | Reject for final locating | Numeric slip margin passes the placeholder check, but the final locator/yaw path must not be slot friction. |
| CR-01-H2-B | Slot fasteners plus shoulder/key positive stop | Preferred | Keeps easy slot-nut adjustment during mock-up, then gives the aligned hard point a mechanical load path. |
| CR-01-H2-C | Slot fasteners plus backing clamp plate | Reserve | Useful if profile wall stiffness or service adjustment is poor, but heavier and less compact. |
| CR-01-H2-D | Through-bolted crossmember or cart member | Conditional reserve | Robust only if the later cart frame deliberately provides access. Do not infer cart holes or members from images. |

## Preferred CR-01-H2-B seed

| Item | Preliminary value |
|---|---:|
| Critical hard-point clamp | Two M8-class T-slot fasteners per hard point |
| Final shear/yaw path | Replaceable shoulder/key/positive stop face |
| Optional repeatability feature | One 6 mm or larger dowel after mock-up alignment |
| Positive stop contact seed | 40 mm width x 8 mm height |
| Positive stop tab seed | 6 mm thick, 25 mm cantilever screen |
| Backing plate | Reserve only |

Screen result:

- Positive stop bearing: about 0.58 MPa.
- Positive stop local tab bending: about 19 MPa.
- Optional 6 mm dowel shear: about 6.6 MPa.
- Optional 6 mm dowel bearing in 8 mm plate: about 3.9 MPa.

These values are low in the current low-load screen. They do not approve geometry, material, bolt grade, slot nut type, torque, washer stack, profile wall bearing, fatigue, wear, or production tolerance.

## Implementation notes for later CAD

- Use slot nuts first to set locator/rest/latch-keeper positions during bench mock-up.
- After alignment, add a shoulder block, keyed plate edge, dowel, or replaceable stop insert so the slot nuts are not the final locating feature.
- Put the positive stop in the direction of expected shear/yaw reaction, and avoid overconstraining the slotted/diamond secondary locator.
- Keep rest pad shims accessible from above or the side.
- Keep latch keepers as preload/uplift retention only. Locators and rest pads carry shear and seating.
- Keep electrical latch/position sensors separate from the mechanical stop/lock path.

## Approval gate

CR-01-H2 is a topology seed only:

```text
PHASE_1_PRELIMINARY_NOT_FOR_FABRICATION
```

Before `APPROVE PARAMETERS`, the exact profile connector family, slot nut/backing plate stack, shoulder/key/dowel geometry, profile wall bearing, service adjustment method, and cart-side access must be reviewed.

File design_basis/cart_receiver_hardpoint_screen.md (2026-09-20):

# CR-01 Cart Receiver Hardpoint Screen

Date: 2026-08-25

Status: Phase 1 preliminary hardpoint screen only. Not approved for fabrication.

Related layout: `design_basis/cart_profile_receiver_layout_screen.md`

Calculation: `calculations/cart_receiver_hardpoint_screen.py`

## Purpose

This screen narrows the CR-01 aluminum-profile receiver hard points:

- locator insert
- rest pad insert
- latch keeper
- insert-to-profile fastening
- local stop/keeper tab

The values below are candidate seeds. They are not hole coordinates, cut lengths, fabrication drawings, or purchase-ready specifications.

## Recommended Hardpoint Set

| Hardpoint | Candidate seed | Role |
|---|---|---|
| Locator insert | 12 mm locator interface in 8 mm local steel insert or hardened bushing | Repeatable X/Y seating and shear transfer |
| Secondary locator | Slotted/diamond receiver around the second locator | Yaw control without overconstraint |
| Rest pad insert | 40 x 30 mm contact seed on 8 mm local pad with shim stack | Vertical seating and height adjustment |
| Latch keeper | 5 mm local steel keeper seed | Retention/preload/uplift only |
| Profile fastening | Two M8-class T-slot fasteners per critical hard point as starting topology | Adjustable mock-up fastening |
| Anti-slip feature | Dowel, key, or positive stop after alignment | Final shear/yaw reference, not slot friction |

## Locator Insert Screen

| Item | Value |
|---|---:|
| Pin/interface diameter seed | 12 mm |
| Local insert thickness seed | 8 mm |
| Master locator shear load | about 154 N |
| Yaw couple force at 520 mm span | about 32 N |
| Combined screen load | about 186 N |
| Bearing stress | about 1.94 MPa |

Interpretation:

- Bulk bearing stress is low in the active PoC load screen.
- Use steel or a hardened bushing at repeated locator contact.
- The unresolved risks are seating wear, lead-in geometry, debris tolerance, and final locator hardware selection.

## Rest Pad Insert Screen

| Item | Value |
|---|---:|
| Pad contact seed | 40 x 30 mm |
| Local insert thickness seed | 8 mm |
| Maximum active screened pad load | about 331 N |
| Contact pressure | about 0.28 MPa |

Interpretation:

- Bulk contact pressure is low.
- Four pads should be shim-adjustable because profile assembly tolerance can otherwise leave one pad unloaded.
- Final design should set a practical shim range and locking method before approval.

## Latch Keeper Screen

| Item | 4-latch placeholder | 2-latch minimum check |
|---|---:|---:|
| Per-latch uplift | about 31 N | about 62 N |
| Keeper seed | 25 mm width x 5 mm thickness | 25 mm width x 5 mm thickness |
| Bearing stress | about 0.25 MPa | about 0.49 MPa |

Interpretation:

- Latch keeper bulk bearing is not the active blocker.
- Latches remain preload/uplift/retention items only.
- Secondary lock and latch-closed sensing remain required.

## Profile Fastener Slip Screen

Candidate placeholder:

| Item | Value |
|---|---:|
| Critical fasteners per hard point | 2 |
| Assumed clamp per fastener | 4000 N |
| Assumed friction coefficient | 0.15 |
| Slip demand | about 186 N |
| Slip capacity | about 1200 N |
| Slip margin | about 6.45x |

Interpretation:

- Even a modest clamp assumption screens above the current active load.
- This does not approve friction as the final locating method.
- After alignment, add dowel, keyed plate, shoulder block, or a positive stop so repeatability does not depend on slot friction.

## Local Keeper/Stop Tab Bending Screen

| Item | Value |
|---|---:|
| Load seed | about 154 N |
| Cantilever seed | 25 mm |
| Plate strip seed | 40 mm wide x 6 mm thick |
| Bending stress | about 16 MPa |

Interpretation:

- Local tab bending is not the likely bulk-strength blocker at this load level.
- Geometry, weld-free/bolt-only mounting, edge distance, and fastener placement still need detail review.

## Current Recommendation

Carry forward `CR-01-H1`:

```text
CR-01-H1:
two 760 mm HFS8-4040 receiver rails,
12 mm master locator interface in 8 mm local steel insert,
slotted/diamond secondary locator,
four 40 x 30 mm shim-adjustable rest pad contacts,
5 mm local steel latch keepers,
two M8-class fasteners per critical hard point for mock-up adjustment,
dowel/key/positive stop after alignment.
```

## Open Items Before Parameter Approval

- Exact slot nut and connector type.
- Whether critical hard points use two bolts, four bolts, or a backing/clamp plate.
- Locator hardware family, lead-in angle, and bushing replaceability.
- Rest pad screw/thread size, shim material, and lock method.
- Latch keeper shape, latch approach direction, handle clearance, secondary lock, and latch-closed sensor.
- Edge distances and whether final inserts need dowel pins after alignment.
- Whether the 8 mm insert / 5 mm keeper / 6 mm tab seeds remain practical with local fabrication tools.

```text
CR-01-H1 HARDPOINT CANDIDATE DEFINED
PHASE 1 PRELIMINARY ONLY
NOT APPROVED FOR FABRICATION
```

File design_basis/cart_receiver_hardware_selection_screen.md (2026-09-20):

# CR-01-H4 cart receiver hardware selection screen

Status: Phase 1 preliminary hardware seed. Not approved for fabrication.

## Purpose

CR-01-H3 separated the four cart receiver hard-point roles. CR-01-H4 narrows those rules into a simple, serviceable hardware seed that can be mocked up without pretending that bolt patterns, fits, or supplier part numbers are already approved.

The retained rule is unchanged:

```text
master locator: fixed X/Y
secondary locator: fixed Y and released X
rest pad: Z seating only
latch keeper: preload/uplift only
```

## Recommended seed: CR-01-H4-S1

| Hard point | Preliminary hardware seed | Function and limit |
|---|---|---|
| Master locator | 12 mm removable round locator pin/bushing, 40 x 8 mm replaceable shoulder stop face, two M8-class T-slot clamp fasteners | Fixes X/Y and takes the primary horizontal locating reaction. One 6 mm dowel may be added only after the mock-up alignment is frozen. |
| Secondary locator | 12 mm nominal locator contact in a 20 mm X-slotted or diamond-style receiver seed, two M8-class T-slot clamp fasteners | Fixes Y only and releases X. A second round X/Y pin or X shoulder stop is prohibited. |
| Rest pad | 40 x 30 mm replaceable contact pad, accessible shim pack, two pad-retention screws | Transfers Z seating only. It must not become a side stop or primary horizontal shear path. |
| Latch keeper | 5 mm local steel keeper, separate mechanical secondary lock, separate sensor bracket reserve | Provides preload/uplift retention only. The latch hook and sensors must not be used for horizontal shear or as mechanical stops. |

Keep at least 25 mm tool access for shim, latch, and sensor service. Reserve a 25 x 25 x 35 mm adjustable envelope for each latch-closed and cart-present sensor location.

## First-order screen at local 3x factor

The screen starts from the CR-01-H2 connector demand of about 186 N and applies the existing 3x local uncertainty factor, yielding about 558 N. These are preliminary comparisons against placeholder material allowables, not a release for fabrication.

| Item | Candidate seed | Result | Interpretation |
|---|---|---:|---|
| Master locator bushing bearing | 12 mm pin x 8 mm bushing | about 5.8 MPa | Below the 80 MPa placeholder steel bearing comparison. Keep the contact as a replaceable bushing/insert, not the aluminum profile itself. |
| Replaceable shoulder stop bearing | 40 mm wide x 8 mm contact | about 1.7 MPa | Below the 80 MPa placeholder steel bearing comparison. |
| Replaceable shoulder stop bending | 8 mm local steel stop, 25 mm cantilever seed | about 32.7 MPa | Below the 120 MPa placeholder steel bending comparison. Final screw pattern and edge distance are still open. |
| Optional post-alignment dowel shear | one 6 mm dowel | about 19.7 MPa | Below the 80 MPa placeholder steel shear comparison. Use only after adjustment is no longer required. |
| Rest-pad contact | 40 x 30 mm pad with 3x Z local factor | about 0.8 MPa | Below the 30 MPa placeholder aluminum contact comparison. This is a direct Z seating check only. |

## Backing-plate rule

Start the first mock-up with the two M8-class T-slot fasteners at each critical hard point so the alignment remains adjustable. Add a local 6 mm steel backing bridge, nominal 60 x 40 mm seed, only if the 30-cycle check shows any of the following:

- Hard-point shift greater than 0.2 mm.
- Fastener torque relaxation greater than 20%.
- Profile-wall marking or indentation.
- Latch-preload change after cycling.

This conditional rule avoids adding metal and access difficulty before the low-load PoC proves it is necessary.

## Open before parameter approval

- Exact T-slot nut family, fastener grade, tightening torque, and profile compatibility.
- Final bushing material, fit, retention, and supplier item.
- Final stop-block screw pattern, edge distance, and installation direction.
- Need for the optional dowel after the 30-cycle mock-up.
- Latch model, secondary-lock form, and sensor model/bracket location.

`CR-01-H4-S1` is a Phase 1 hardware selection seed only. It is not an approved fabrication drawing, an assembly instruction, or a purchasing release.

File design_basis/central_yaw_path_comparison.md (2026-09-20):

# Central Yaw Path Comparison

Status: preliminary Phase 0 concept comparison. Not approved for fabrication.

Current-use note: after the 2026-08-25 user clarification, the active review baseline is the low-load 10 kg payload / 10 kg cart / +/-3 deg case in `design_basis/user_confirmed_scope_2026-08-25.md` and `outputs/reports/final_candidate_parameter_pack.md`. The earlier 90 kg yaw case is retained only as an archived conservative sensitivity.

## Purpose

Previous checks showed that small universal joints can provide enough articulation angle but cannot serve as the sole yaw-torque path. This note compares alternative central yaw-torque paths while preserving the required platform DOF:

- Allowed: Z translation, pitch, roll.
- Constrained: X translation, Y translation, yaw.

The comparison is implemented in `calculations/central_yaw_path_comparison.py`.

## Required Case

The active screen uses the current user-confirmed low-load case:

| Item | Value |
|---|---:|
| Total lifted mass | 42 kg |
| Horizontal acceleration | 0.25 g |
| Design factor | 1.5 |
| CG offset | 50 mm X, 50 mm Y |
| Operating yaw torque | 10.9 Nm |
| Peak/design yaw torque | 16.4 Nm |
| Required Cardan/gimbal articulation with margin at +/-3 deg pitch/roll | 6.2 deg |

This is still a screening case, not a certified load case.

Archived conservative sensitivity:

| Item | Value |
|---|---:|
| Total lifted mass | 90 kg |
| Horizontal acceleration | 0.5 g |
| Design factor | 2.0 |
| CG offset | 100 mm X, 100 mm Y |
| Operating yaw torque | 124.8 Nm |
| Peak/design yaw torque | 249.6 Nm |

## Compared Concepts

| ID | Concept | Screen result | Phase 0 rank |
|---|---|---|---:|
| YAW-A | Keyed square slide with two-axis gimbal torque bypass | Pass preliminary load screen | 1 |
| YAW-D | Dual parallel anti-yaw guides with top compliance | Pass load only; reserve | 2 |
| YAW-C | Single 16 mm commercial ball spline | Passes low-load torque only; reserve | 3 |
| YAW-B | Oversized direct-torque universal joint | Pass torque/angle screen; oversized reserve | 4 |

## YAW-A: Keyed Square Slide With Gimbal Torque Bypass

Direction:

- The central square telescoping guide carries yaw torque.
- The upper two-axis gimbal allows pitch/roll but does not interrupt yaw torque transmission.
- Yaw torque passes through the keyed/anti-rotation tube and its fastened yokes, not through a small U-joint.

Screen result:

- At 16.4 Nm peak/design torque, the 50 x 3 mm square-tube estimate gives about 1.24 MPa torsional shear and 0.022 deg twist over 190 mm.
- With a 50 mm torque-couple separation, the key/facing couple force is about 328 N.
- With 80 mm overlap and a 10 mm contact width, preliminary contact pressure is about 0.41 MPa.

Interpretation:

- This is the preferred Phase 0 direction.
- The concept remains open because backlash, wear, side-load, sliding clearance, contamination, gimbal-axis implementation, and connection fasteners are not solved.
- A physical mock-up is required before fabrication CAD.

## YAW-B: Oversized Direct-Torque Universal Joint

Reference source:

- Ruland US32-22MM-20MM-F, rated torque 485.8 Nm, peak torque 2429.2 Nm, max operating angle 45 deg.

Screen result:

- Rated torque margin against the 10.9 Nm operating torque is very large.
- Peak torque margin against the 16.4 Nm peak/design torque is very large.
- Angle margin at the +/-3 deg pitch/roll screen is large.

Interpretation:

- This is the reserve torque-capable Cardan direction.
- It is probably large for the current central stack: 50.7 mm OD and 139.7 mm length.
- Shaft/key/clamp details, backlash, side load, cost, and package height remain unresolved.

## YAW-C: Single 16 mm Commercial Ball Spline

Reference source:

- MISUMI No.000127 ball spline table lists the No.16 static torque rating as 93 Nm and dynamic torque rating as 51 Nm.

Screen result:

- Dynamic torque margin against 10.9 Nm: about 4.7.
- Static torque margin against 16.4 Nm: about 5.7.

Interpretation:

- Keep a single 16 mm ball spline as a reserve, not the preferred central yaw path.
- It is no longer torque-blocked under the low-load screen, but it would change cost, package, and overconstraint risk.
- Pitch/roll still requires a separate gimbal isolation scheme.

## YAW-D: Dual Parallel Anti-Yaw Guides

Reference source:

- HIWIN MGN15H block rating already in the source register: dynamic 6370 N, static 9110 N.

Screen result:

- With 400 mm guide separation, operating couple force is about 27 N.
- Peak/design couple force is about 41 N.
- These are small compared with the reference guide load ratings.

Interpretation:

- Load capacity is not the issue.
- This is a reserve concept only because it widens the mechanism, adds alignment sensitivity, and can overconstrain pitch/roll unless top compliance/gimbals are explicit.

## Current Decision

Carry forward YAW-A as the preferred central yaw path:

```text
Preferred: keyed square telescoping guide carries yaw torque
Required: two-axis gimbal permits pitch/roll without interrupting yaw path
Rejected: small U-joint as sole yaw-torque path
Reserve: oversized direct-torque Cardan or dual anti-yaw guides
Reserve for now: single 16 mm ball spline
```

## Open Items

Before parameter approval:

1. Define the gimbal/yoke topology that lets pitch/roll move while preserving yaw torque transfer.
2. Define anti-yaw key/contact faces, overlap, wear pads, preload/clearance, and contamination protection.
3. Check backlash and allowable yaw compliance.
4. Check side load from off-axis actuator and payload cases.
5. Build a low-risk physical mock-up before detailed metal fabrication CAD.

```text
CENTRAL YAW PATH COMPARED
YAW-A PREFERRED DIRECTION
CENTRAL GUIDE STILL CRITICAL_OPEN
NOT READY FOR APPROVE PARAMETERS
```

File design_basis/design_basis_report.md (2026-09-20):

# Phase 0 Web-Based Design Basis Report

Status: concept approved for Phase 2 detailed CAD on 2026-08-26. Preliminary; not approved for fabrication.

## 1. Current conclusion

The Phase 0 source structure and traceability are useful, but the previous wording was too close to a parameter approval package. The correct current state is:

```text
PHASE 0 DIRECTION REVIEWED
PARAMETER TABLE REVISED AFTER FEEDBACK
USER-CONFIRMED LOW-LOAD +/-3 DEG BASELINE
ALUMINUM PROFILE CART RECEIVER DIRECTION RECORDED
CR-01-H3 CONNECTOR STACK RULES SCREENED
CR-01-H4 HARDWARE SEED SCREENED
JNT-BR-01 HRT8E BRACKET SEED SCREENED
APPROVE CONCEPT RECEIVED 2026-08-26
PHASE 2 DETAILED CAD BASELINE GENERATED
BENCH EVIDENCE PENDING BEFORE DESIGN FREEZE
NOT APPROVED FOR FABRICATION
```

The concept direction can remain:

- Three-actuator upper platform concept.
- User-confirmed carried material payload target: 10 kg.
- User-confirmed expected empty cart mass: about 10 kg, with the cart designable around the module.
- User-confirmed disconnected leveling-device height envelope: 250 to 300 mm.
- User-confirmed Pitch/Roll target: +/-3 deg.
- User-preferred cart receiver fabrication direction: CR-01 two-rail aluminum profile receiver kit with CR-01-H1 local metal hard points, CR-01-H2-B connector / positive-stop topology, CR-01-H3 hardpoint-specific stack rules, and CR-01-H4-S1 mock-up hardware seed.
- +/-5 deg as future stretch only, not a current requirement.
- +/-8 deg as sensitivity only, not a baseline target.
- Mechanical locating and latching for cart coupling.
- Independent electrical limits and mechanical stops.

But component names and geometry values are still candidates or assumptions, not frozen selections.

## 2. Feedback findings accepted

The external feedback identified five material issues, all accepted:

1. The central guide mechanism is not solved. It is now marked `critical_open`.
2. Lift and pitch/roll use the same actuator stroke budget. A coupled workspace screen was added.
3. The 12 V Firgelli actuator candidate conflicts with a blanket 24 V bus target. Power architecture is now unresolved.
4. The 10 kg payload must mean additional material payload, not total lifted mass.
5. Component candidates were marked as selected too early. The parameter table now uses `CANDIDATE`, `UNRESOLVED`, `ASSUMED`, and `SELECTED_CONCEPT` more carefully.

## 3. Governing constraints

- Scope is limited to the leveling/lifting upper module, universal lower mounting interface, and mechanical cart coupling.
- Active upper-platform DOF are Z, pitch, and roll only.
- X, Y, and yaw must be mechanically constrained.
- Cart engagement must use mechanical locating and latching. Electromagnets cannot be the primary lock.
- Electrical limit switches and mechanical stops must be independent.
- Cart dimensions, materials, mass, and hole locations may not be inferred from images.
- The module is not for carrying people, and no certification claim is made.

## 4. Revised calculation basis

### 4.1 Lifted mass

The material payload is not the lifted mass. Actuator loads must use:

```text
total_lifted_mass =
moving_structure_mass
+ empty_cart_mass
+ material_payload_mass
```

Current user-confirmed PoC analysis sweeps:

- Material payload: 5 and 10 kg primary; 20 kg archived sensitivity only.
- Empty cart mass: 10 kg primary; 20 and 30 kg archive/check sensitivity.
- Moving structure mass: 15 and 22 kg.
- Design factor: 1.5 baseline; 2.0 sensitivity.
- Payload/CG offset: 0 and 50 mm baseline; 100 mm sensitivity.

`calculations/user_confirmed_baseline.py` now records the 2026-08-25 user clarification.

### 4.2 Actuator force

The load distribution screen remains:

```text
W_design = total_lifted_mass * g * design_factor

[ 1   1   1  ] [R1]   [W_design]
[x1  x2  x3 ] [R2] = [W_design * x_cg]
[y1  y2  y3 ] [R3]   [W_design * y_cg]

F_actuator_i = R_i / cos(theta_i)
```

This is a screening equation only. It does not replace pin, bracket, bolt, buckling, fatigue, shock, side-load, backlash, or finite-element checks.

### 4.3 Coupled workspace

The previous simple length sweep has been supplemented by `calculations/combined_workspace.py`.

With the current CAD geometry:

- At 5 mm actuator end margin, the minimum supported symmetric pitch/roll angle across 0-100 mm lift is about 5.75 deg.
- At 15 mm actuator end margin, the minimum supported symmetric pitch/roll angle across 0-100 mm lift drops to about 3.5 deg.
- At minimum lift and +/-3 deg, the 15 mm-margin screen leaves only about 2.5 mm effective margin.
- At minimum lift and +/-5 deg, the 15 mm-margin screen fails.
- +/-8 deg remains sensitivity only.

The current 250 mm comparison geometry therefore could not claim `100 mm lift + +/-3 deg pitch/roll at all heights` without more end-stroke, mechanical-stop, control-overshoot, tolerance, guide-mobility, and joint-angle evidence.

### 4.4 Selected pre-CAD operating-window candidate

`calculations/workspace_operating_window_screen.py` compares the old 250 mm layout to the approved higher collapsed pose. `WS-01-H20` is the selected Phase 2 CAD baseline:

- 270 mm disconnected/collapsed device height, within the user-confirmed 250 to 300 mm envelope.
- 0 to 100 mm lift and every nine `-3/0/+3 deg` pitch/roll combination.
- 195 mm outer and 220 mm inner keyed-guide candidate, producing 88 mm minimum overlap against the 80 mm target.
- 334 to 508 mm actuator soft operating window, with 11.13 mm minimum remaining reserve at the lower combined corner.

`calculations/travel_limit_hierarchy_screen.py` separates the planned command window from electrical and mechanical protection: command 334/508 mm, electrical targets 329/513 mm, and guarded mechanical-stop boundaries 324/518 mm. These are actuator-length planning values. CAD must create external physical shoulders/collars and real switches, then prove their contact order and measured overrun. They are not fabrication dimensions.

## 5. Revised parameter envelope

| Area | Revised status |
|---|---|
| Three-actuator architecture | Concept direction retained |
| Firgelli F-SD-H-450-12V-8in Hall | Leading low-load PoC candidate |
| DESTACO 323-R latch | Candidate only |
| HFS8-4040 frame | Candidate profile, exact procurement code open |
| Aluminum profile cart receiver | CR-01 two-rail HFS8 receiver kit candidate; CR-01-H1 hardpoint seed, CR-01-H2-B connector topology, CR-01-H3 connector stack rules, and CR-01-H4-S1 hardware seed added |
| BNO085 | Candidate PoC IMU |
| WT901C | Candidate packaged tilt sensor; exact variant to confirm |
| 10 kg payload | User-confirmed carried material payload target |
| 10 kg empty cart | User-confirmed primary cart basis; 20/30 kg retained only as sensitivity |
| 22 kg moving structure | Current upper PoC moving-structure sweep value |
| Disconnected device height 250-300 mm | User-confirmed envelope before cart coupling |
| Neutral/collapsed height | WS-01-H20 270 mm Phase 2 CAD baseline, inside 250-300 mm user envelope |
| 100 mm lift | Selected grid passes with +/-3 deg; physical actuator/guide/stop evidence still required |
| +/-3 deg pitch/roll | User-confirmed baseline; YAW-A axis order and workspace screened, physical mock-up still required |
| Actuator end joint | HRT8E-style rod end for +/-3 baseline with JNT-BR-01 centered double-shear bracket seed; high-angle link ball reserve |
| 24 V bus | Not required unless actuator is reselected |
| 4000 N upgrade threshold | Removed; upgrade criterion is derived from force/package/speed/duty/control checks |

## 6. Critical open item: central guide

The current phrase `central keyed telescoping guide plus Cardan accommodation` is a concept, not a solved mechanism.

The next-step mobility screen in `calculations/mobility_analysis.py` refines this:

- A keyed vertical telescoping guide with a yaw-transmitting two-axis Cardan has constraint rank 3, leaving Z, pitch, and roll.
- A rigid keyed slide without Cardan has constraint rank 5, leaving only Z and therefore binding pitch/roll.
- The actuator-length Jacobian rank is 3 in the screened +/-3, +/-5, and +/-8 deg ranges, so the length mapping is not the dominant risk.
- The physical risk remains Cardan/yaw torque transmission, actuator joint misalignment, side-load, guide overlap, and stop/clearance allocation.

Before parameter approval, the project must define:

- Actuator upper and lower joint types.
- Central guide lower joint type.
- Central guide upper joint type.
- Cardan axis directions.
- Which component constrains yaw.
- Whether pitch/roll induce guide side-load.
- Joint maximum articulation over all poses.
- Whether the constraint set is overconstrained or underconstrained.
- A full-pose mobility check, ideally using a Jacobian/rank or equivalent constraint analysis.
- A physical mock-up or low-risk bench test before metal fabrication.

This is the largest mechanical risk. If it is not resolved, the real mechanism can bind even if all actuator force calculations pass.

Current numerical flags:

- Cardan combined tilt is 4.24 deg at +/-3 deg, 7.07 deg at +/-5 deg, and 11.30 deg at +/-8 deg.
- The current 8 deg design angle / 10 deg hard stop passes the user-confirmed +/-3 deg baseline and treats +/-5 deg as hard-stop sensitivity only.
- Lower actuator joint deviation reaches 10.94 deg at +/-3 deg and 13.85 deg at +/-5 deg.
- Current guide overlap minimum is 83 mm against an 80 mm preliminary target, which is too close for approval.

### 6.1 Joint candidate follow-up

`calculations/joint_candidate_screen.py` adds a preliminary candidate filter:

- Angular margin: 2 deg beyond calculated joint deviation.
- Static load screen: candidate static capacity >= 2 x calculated maximum actuator axial force.

Screen result:

- Single-axis clevis is rejected as the primary actuator end joint because the current motion is spatial.
- MISUMI PHSOSM8 is screened out for the primary actuator joint.
- MinebeaMitsumi HRT8E passes the current +/-3 deg baseline screen and is now the leading simple actuator joint candidate if packaging preserves articulation.
- MISUMI RBLD8-style high-angle link ball remains a reserve if the HRT8E-style package loses angular margin.
- Ruland-style universal joints are useful as a yaw-transmitting central Cardan component-family reference by angle only. Exact torque, backlash, axial/radial load, and mounting are still open.

### 6.2 Joint detail follow-up

`calculations/joint_detail_screen.py` adds first-order packaging checks for the joint load path.

Actuator joint result:

- Pin double-shear and lug bearing stresses are not the obvious bottleneck in the current screen.
- Threaded-stud cantilever bending is the bottleneck if the bracket force line is offset.
- At the archived +/-5 deg stretch screen under the current low-load mass basis, an M8 link-ball style joint with a 10 mm unsupported standoff gives about 407 MPa preliminary bending stress.
- An M12 upsize reduces that to about 119 MPa and passes the placeholder 150 MPa numeric screen, but remains a packaging reserve rather than a reason to use a threaded shank as a spacer.
- The actuator bracket must route force through the ball center or use a boxed/double-shear arrangement that avoids using the threaded shank as a cantilever spacer.
- JNT-BR-01 corrects the HRT8E actuator-axis screen to the 5.29 kN axial static value, not the 26.77 kN radial catalog value. The active +/-3 deg/DF 2.0/100 mm eccentricity screen is about 972 N; the existing 2x static comparison leaves about 2.72x axial margin.
- JNT-BR-01 now uses the official HRT8E 8/23/11 mm envelope, two 8 mm steel lugs, one 8 mm double-shear pin and an 18 mm loaded inner-lug support span. The regenerated placeholder comparison gives about 8.7 MPa pin shear, 78.5 MPa pin bending, 13.7 MPa lug bearing and 38.5 MPa lug-root bending. Physical V-01 articulation remains open.
- Required articulation is about 12.94 deg against HRT8E's 14 deg catalog value, so a physical full-14-deg no-contact check is a candidate-retention condition, not a completed proof.

Central yaw result:

- The old conservative yaw-torque screen using 90 kg total lifted mass, 0.5 g horizontal acceleration, DF 2.0, and 100/100 mm CG offset gave about 125 Nm yaw torque and about 250 Nm peak/design. It is no longer the primary design target after the 2026-08-25 user clarification.
- The user-confirmed low-load PoC screen gives about 16 Nm design yaw torque with the 10 kg cart basis. The earlier 24 Nm value is retained only as a 30 kg cart sensitivity.
- Under the new PoC screen, force margin is no longer the obvious blocker. The unresolved part is the gimbal/Cardan/key/fastener/backlash connection path.

### 6.3 Central yaw path comparison

`calculations/central_yaw_path_comparison.py` compares four yaw-torque path concepts.

Current ranking for a fabrication-first low-load PoC:

1. YAW-A: keyed square telescoping guide carries yaw torque, while the two-axis gimbal permits pitch/roll without interrupting the yaw path.
2. YAW-D: dual parallel anti-yaw guides with explicit top compliance/gimbal, reserve only if YAW-A backlash is unacceptable.
3. YAW-C: single 16 mm commercial ball spline, reserve only because it adds procurement/package complexity.
4. YAW-B: oversized direct-torque U-joint, archived as too large/complex for the low-load PoC unless all simpler paths fail.

Key values:

- User-confirmed PoC design yaw torque: about 16 Nm.
- YAW-A contact screen: about 328 N couple force and 0.41 MPa contact pressure with 80 mm overlap and 10 mm contact width.
- Heavy-cart 30 kg sensitivity: about 24 Nm design yaw torque, 484 N couple force, and 0.60 MPa contact pressure.
- Ruland US32 reference is now oversized for the simplified PoC.
- MISUMI No.16 ball spline torque is no longer the main blocker under the low-load screen, but it still adds pitch/roll isolation and procurement complexity.

Current Phase 0 direction is therefore to carry forward YAW-A, not a small U-joint or single 16 mm ball spline, while keeping the central guide `critical_open` until backlash, wear, side-load, key/contact geometry, and a mock-up are complete.

### 6.4 YAW-A candidate parameter definition

`calculations/yaw_a_architecture_screen.py` defines the preferred YAW-A architecture in candidate-parameter form.

Mobility result:

- YAW-A constrains tx, ty, and rz.
- YAW-A leaves tz, rx, and ry.
- A rigid keyed slide without a gimbal binds pitch/roll.
- A loose spherical joint without a yaw lock leaves yaw unconstrained.

Candidate parameters:

| Parameter | Candidate |
|---|---:|
| Gimbal design angle | 8 deg |
| Gimbal hard stop | 10 deg |
| Preferred total yaw clearance | <= 0.2 mm |
| Maximum total yaw clearance | <= 0.3 mm |
| Preferred yaw freeplay | <= 0.25 deg |
| Maximum yaw freeplay | <= 0.5 deg |
| Anti-yaw contact width | >= 10 mm |
| Minimum engaged overlap | >= 80 mm |
| Preferred engaged overlap | >= 100 mm |
| Yaw couple arm through gimbal/yoke | >= 50 mm |
| Gimbal/yoke pin diameter | >= 10 mm |
| Gimbal/yoke lug thickness | >= 8 mm |

These values are candidates for the low-load +/-3 deg review package, not approved fabrication parameters.

## 7. Cart profile receiver screen

`calculations/cart_profile_receiver_screen.py` adds a first pass for the user-preferred aluminum-profile cart receiver.

Current candidate:

| Item | CR-01 candidate |
|---|---:|
| Receiver type | two longitudinal aluminum-profile rails |
| Profile basis | HFS8-4040 or equivalent sourced 40 mm profile |
| Receiver zone | 760 mm x 560 mm |
| Rest pad span | 620 mm x 520 mm |
| Locator topology | one master locator plus one slotted/diamond secondary locator |
| Locator X span | 520 mm |
| Latch count | 2 minimum; 4 placeholder |
| Screened receiver kit mass | about 4.50 kg |

The HFS8 rectangular subframe reserve screens at about 6.43 kg. It remains possible, but it consumes too much of the 10 kg empty-cart mass basis unless the future cart frame needs a self-contained receiver.

Current CR-01 load screen:

- Active worst rest-pad maximum load: about 331 N.
- Active worst rest-pad minimum load: about 81 N, so all four pads remain compressive in the simplified active screen.
- Master locator single-point shear if it carries all horizontal shear: about 154 N.
- Yaw couple force at 520 mm locator span: about 32 N.
- Per-latch uplift with four latches: about 31 N.

This keeps bulk loads low. The remaining risks are connector stiffness, slot slip, local wear, insert plate details, and latch/locator geometry.
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

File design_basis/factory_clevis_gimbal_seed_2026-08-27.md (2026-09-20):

# JNT-CG-01 factory-eye nested-gimbal seed

Status: `MEASURED_MOCKUP_SEED - NOT APPROVED FOR FABRICATION`

## Why the joint changed

The selected Firgelli actuator has integral 8.2 mm mounting holes at both ends. The archived family drawing also shows a 20 mm eye OD, but it is for the 220 lbf 2-inch model and is not a selected-model fabrication drawing. A serial clevis-to-HRT8E adapter was screened with a provisional 32 mm extension at each end. At the worst +/-3 degree position, the effective actuator pin distance falls below the 319 mm catalogue retracted length, so the serial topology is rejected for the current support geometry.
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

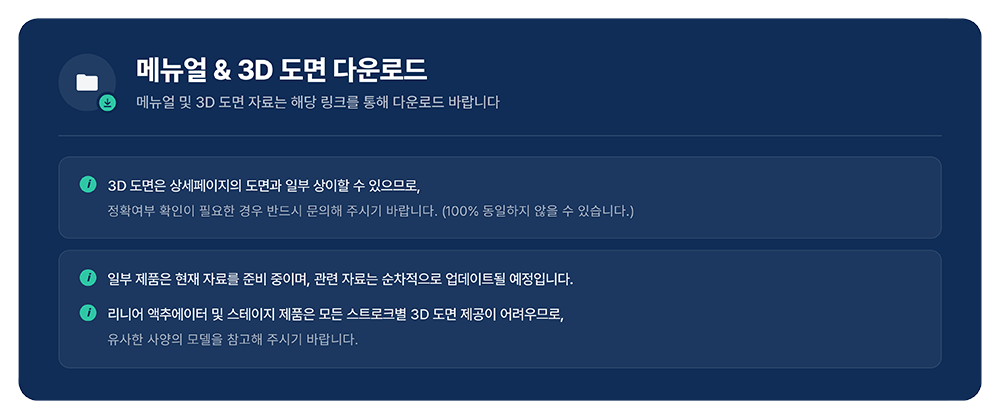
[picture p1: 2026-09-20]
web_research/evidence/2026-08-31/LM4075OE_3D_download_1000x419.png

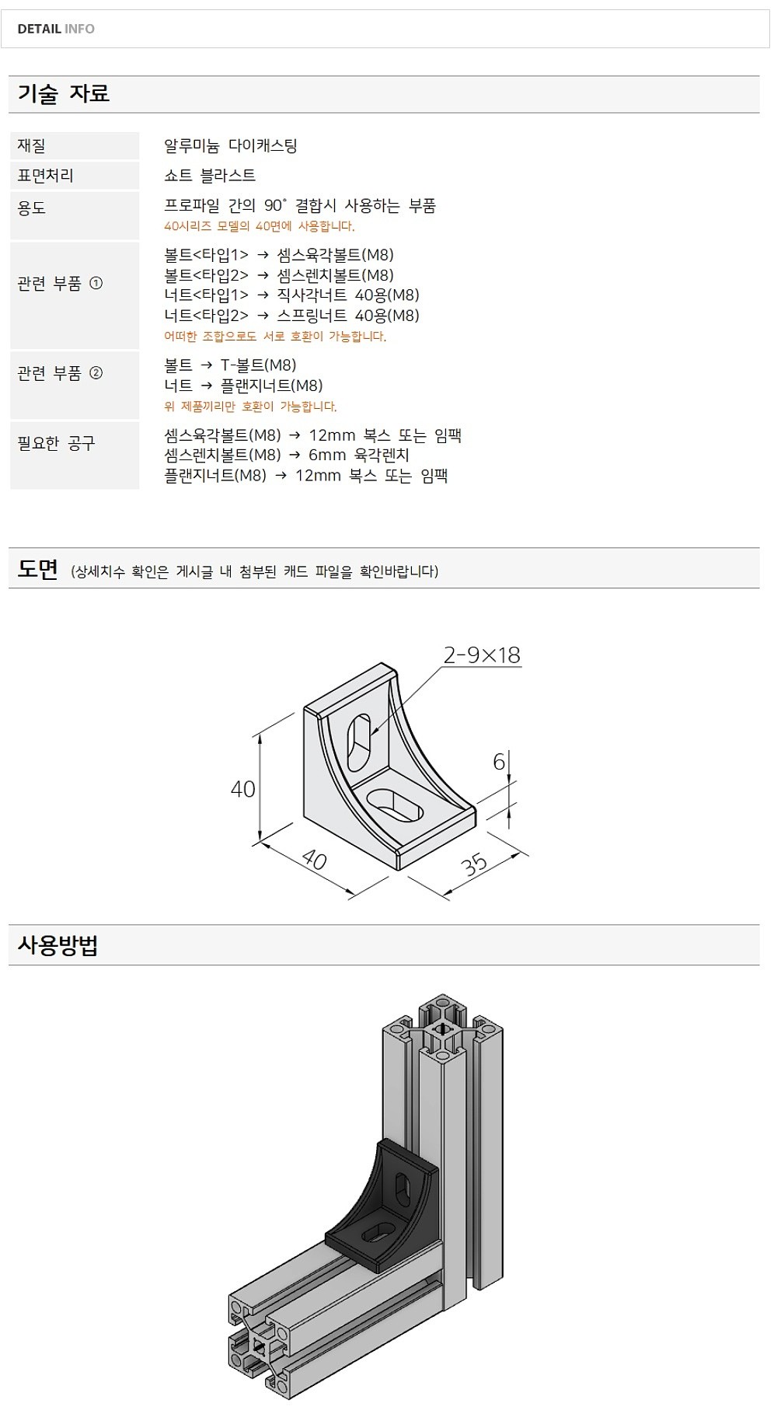
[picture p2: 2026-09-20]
web_research/evidence/2026-08-31/NAVIMRO_4035_bracket_detail_996x1810.jpg

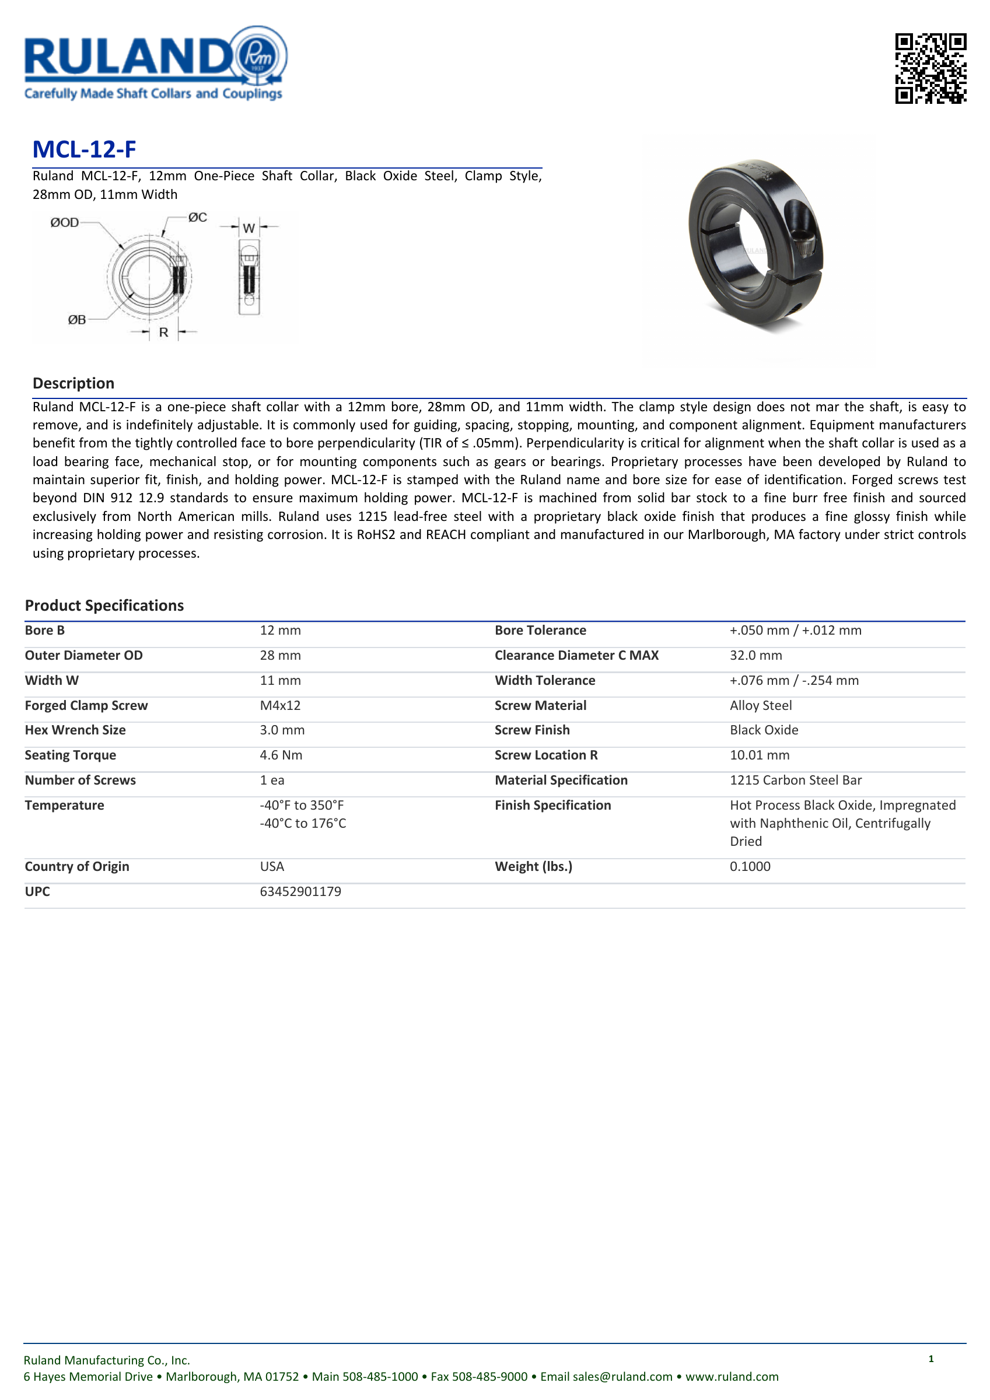
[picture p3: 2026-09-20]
web_research/evidence/2026-09-05/m2r2_fasteners/ruland_mcl12f_p1.png

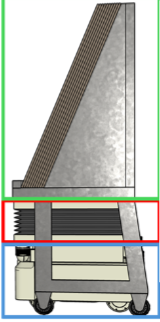
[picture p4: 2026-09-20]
references/스크린샷 2026-08-23 192323.png

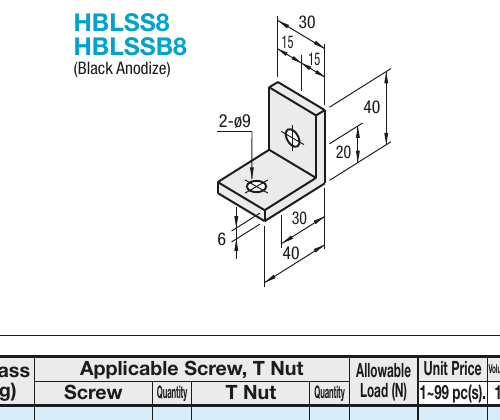
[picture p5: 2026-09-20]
web_research/evidence/2026-09-05/m2r2_fasteners/bracket_crop.png

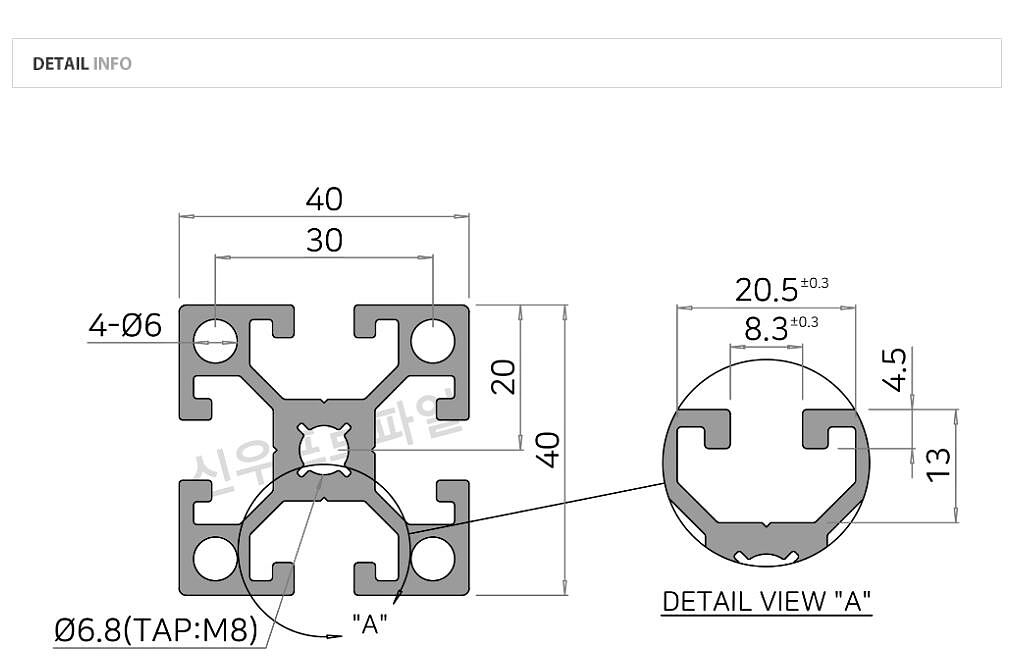
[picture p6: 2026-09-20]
web_research/evidence/2026-08-31/NAVIMRO_DNF4040_detail_1024x672.jpg

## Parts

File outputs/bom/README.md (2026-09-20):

# BOM status

## Active direction

The active 2026-09-01 concept is the manually adjustable three-strut 3-RPS.
No final orderable manual BOM exists yet.

Read:

- `../../requirements/current_manual_scope_2026-09-01.md`
- `../../design_basis/manual_adjustable_3rps_baseline_2026-09-01.md`
- `../../procurement/manual_3rps_bom_delta_2026-09-01.csv`

## Archived powered workbook

`Profile_Radial_3RPS_RevD_Final_BOM_2026-09-01.xlsx` is archived and must not
be used for ordering. It records the last LM4075OE/DMD-150/IMU powered design.

```text
POWERED_VARIANT = ARCHIVED_DO_NOT_ORDER
PURCHASE_RELEASE = FALSE
FABRICATION_RELEASE = FALSE
```

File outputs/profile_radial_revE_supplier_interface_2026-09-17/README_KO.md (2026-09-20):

# Rev E 공급품 인터페이스 CAD

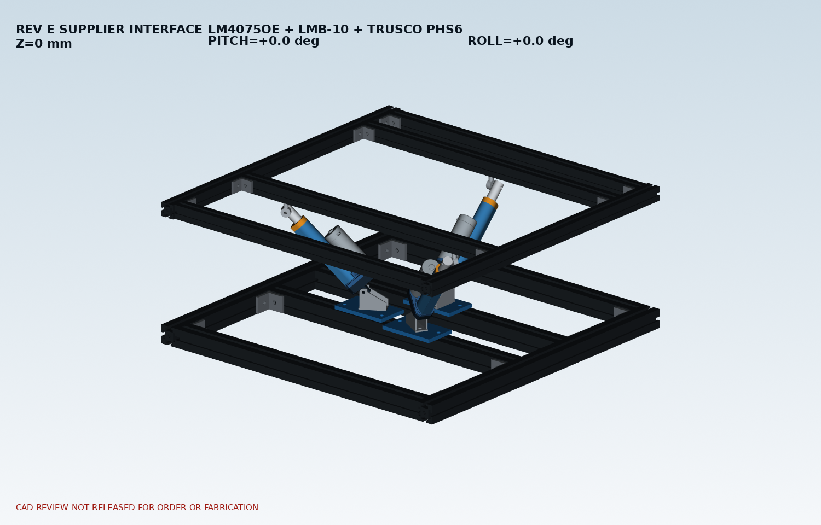
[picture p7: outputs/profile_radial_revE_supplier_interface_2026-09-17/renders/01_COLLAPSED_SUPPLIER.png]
접힌 자세


## 적용 부품

- 액추에이터: Motorbank `LM4075OE-1075`, 24 V, 100 mm, 공급사 STEP 적용
- 하부 브래킷: Motorbank `LMB-10`, 공개도면 외곽 적용
- 상부 로드엔드: 한국미스미 TRUSCO `PHS6`, 발주코드 `280-7599`, 공개치수 외곽 적용
- 프레임과 120 x 70 x 8 mm 하부 어댑터는 기존 승인 Rev E 배치를 유지

## 최소 수정

TRUSCO PHS6의 보수적 축방향 외곽과 액추에이터 전단 아이가 복합 ±3도 자세에서 미세하게 겹쳐, PHS6를 공통 피벗 핀 축 방향으로 1.5 mm 바깥쪽 이동했다. 실제 조립에서는 M6용 1.5 mm 간격 와셔 또는 등가 shim stack을 사용한다. 프레임이나 어댑터 형상은 변경하지 않았다.

## 디지털 검증 결과

- 자세: Z 0/25/50 mm × pitch -3/0/+3도 × roll -3/0/+3도 = 27자세
- 액추에이터 핀 중심거리 전체 범위: 210.771741–276.937115 mm
- 액추에이터 허용 범위: 205–305 mm
- 최대 비의도 실체 교차체적: 0 mm³
- 결과: 27자세 디지털 조립/간섭검사 PASS

수평 자세의 핀 중심거리는 Z=0에서 224.207493 mm, Z=25에서 242.886805 mm, Z=50에서 262.619497 mm이다.

## STEP 파일

- `step/Profile_Radial_3RPS_RevE_SUPPLIER_COLLAPSED.step`
- `step/Profile_Radial_3RPS_RevE_SUPPLIER_NEUTRAL.step`
- `step/Profile_Radial_3RPS_RevE_SUPPLIER_RAISED.step`
- `step/Profile_Radial_3RPS_RevE_SUPPLIER_P3_R3.step`
- `step/Profile_Radial_3RPS_RevE_SUPPLIER_P3_RM3.step`
- `step/A1_LM4075OE_LMB10_TRUSCO_PHS6_INTERFACE_DETAIL.step`

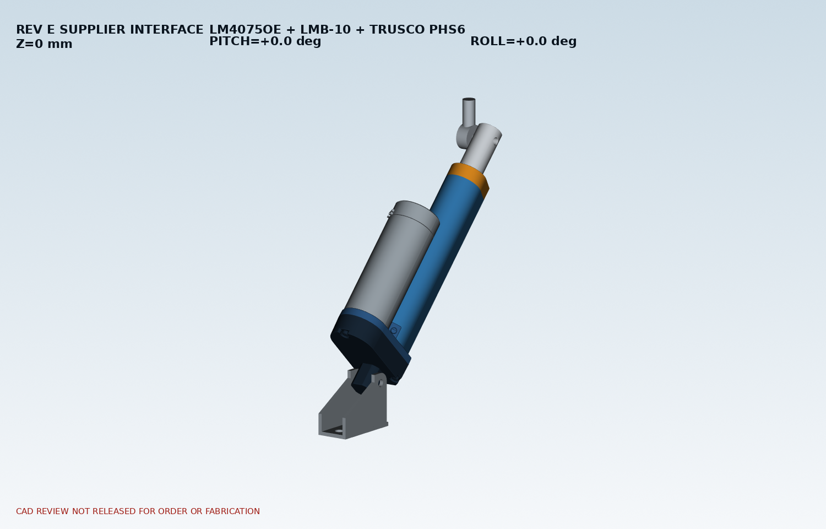
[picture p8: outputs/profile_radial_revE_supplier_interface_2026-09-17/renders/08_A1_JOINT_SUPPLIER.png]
A1 공급품 인터페이스


## 조립 순서

1. 하부 120 x 70 x 8 mm 어댑터를 프로파일에 느슨하게 체결한다.
2. LMB-10을 36 mm 홀 피치에 맞추고 두 볼트를 체결한다.
3. 액추에이터 후단 아이를 LMB-10 내폭 20 mm 사이에 넣고 하부 핀을 삽입한다.
4. 상부 PHS6를 정렬하되 액추에이터 전단 아이에서 핀 축 방향으로 1.5 mm 간격을 둔다.
5. M6 피벗 핀/볼트를 삽입하고 간격 와셔를 설치한다.
6. 세 액추에이터의 핀 중심거리를 약 242.9 mm로 맞춘 뒤 상부 프레임을 지지 블록 위에서 결합한다.
7. 손으로 ±3도 범위를 천천히 움직여 걸림이 없는지 확인한 후 전원을 연결한다.

## 남은 실물 확인

- PHS6 미스미 페이지에는 CAD 다운로드가 없으므로 축방향 폭 10 mm를 보수적 외곽으로 사용했다.
- 수령 후 LMB-10 내폭, PHS6 축방향 폭, 액추에이터 아이 폭을 캘리퍼로 확인한다.
- 체결품과 핀은 이번 공급품 외곽 STEP에서 제외했다. M6 피벗 길이와 와셔 조합은 실측 후 확정한다.
- 기존 기계식 스토퍼 그룹은 내부 리미트만 사용한다는 시제품 범위에 따라 이 출력에서 제외했다.
- 디지털 PASS는 실제 조립, 체결 토크, 배선, 무부하 시운전을 대신하지 않는다. 구매·가공 최종 릴리스는 실물 치수 확인 뒤 결정한다.

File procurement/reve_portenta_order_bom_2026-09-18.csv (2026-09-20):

발주구분 | ID | 분류 | 품목 | 규격 | 사용수량 | 주문수량 | 주문단위 | 공급처 | 상품번호/형번 | 단가(VAT포함) | 확장금액 | 가격기준 | 납기 | 주문상태 | 대체허용 | CAD/조립확인 | 구매URL | 주문/조립 메모 | 확인일 | 출하구분 | 증빙 | 구매릴리스 | 예산판정
BASE | S01 | 구조 | 하부 4040 프로파일 700 mm | DNF4040/M8, 40×40, 흑색, 직각절단 | 2 | 2 | EA | 나비엠알오 | K92787708 | 21989 | 43978 | VAT포함 화면가 | 약 3영업일 | ORDER_BASE | 동등 규격 허용 | CAD 수량 PASS | https://www.navimro.com/p/K92787708/ | 하부 외곽 레일 2개. 주문 시 700 mm 재확인 | 2026-09-17 | 기존 9/17 BOM 유지; 국내재고·출하 재확인 | procurement/reve_final_order_bom_2026-09-17.csv (기존 계획가 포함) | HOLD_VENDOR_REPLY | 판정 보류
BASE | S02 | 구조 | 하부 4040 프로파일 620 mm | DNF4040/M8, 40×40, 흑색, 직각절단 | 4 | 4 | EA | 나비엠알오 | K92787705 | 19789 | 79156 | VAT포함 화면가 | 약 3영업일 | ORDER_BASE | 동등 규격 허용 | CAD 수량 PASS | https://www.navimro.com/p/K92787705/ | 하부 횡재 4개. 주문 시 620 mm 재확인 | 2026-09-17 | 기존 9/17 BOM 유지; 국내재고·출하 재확인 | procurement/reve_final_order_bom_2026-09-17.csv (기존 계획가 포함) | HOLD_VENDOR_REPLY | 판정 보류
BASE | S03 | 구조 | 상부 3030 프로파일 700 mm | DNF3030-6/M6, 30×30, 직각절단 | 2 | 2 | EA | 나비엠알오 | K42296106 | 7689 | 15378 | VAT포함 화면가 | 약 3영업일 | ORDER_BASE | 동등 규격 허용 | CAD 수량 PASS | https://www.navimro.com/p/K42296106/ | 상부 외곽 레일 2개. 슬롯6/M6 확인 | 2026-09-17 | 기존 9/17 BOM 유지; 국내재고·출하 재확인 | procurement/reve_final_order_bom_2026-09-17.csv (기존 계획가 포함) | HOLD_VENDOR_REPLY | 판정 보류
BASE | S04 | 구조 | 상부 3030 프로파일 640 mm | DNF3030-6/M6, 30×30, 직각절단 | 4 | 4 | EA | 나비엠알오 | K42296071 | 6589 | 26356 | VAT포함 화면가 | 약 3영업일 | ORDER_BASE | 동등 규격 허용 | CAD 수량 PASS | https://www.navimro.com/p/K42296071/ | 상부 횡재 4개. 주문 시 640 mm 재확인 | 2026-09-17 | 기존 9/17 BOM 유지; 국내재고·출하 재확인 | procurement/reve_final_order_bom_2026-09-17.csv (기존 계획가 포함) | HOLD_VENDOR_REPLY | 판정 보류
BASE | S05 | 구조 | 40시리즈 직각 브래킷 | 4035 다이캐스트 | 8 | 8 | EA | 나비엠알오 | K92782553 | 913 | 7304 | VAT포함 화면가 | 재고 확인 | ORDER_BASE | 동등 규격 허용 | CAD 수량 PASS | https://www.navimro.com/p/K92782553/ | 하부 내부 코너 8곳 | 2026-09-17 | 기존 9/17 BOM 유지; 국내재고·출하 재확인 | procurement/reve_final_order_bom_2026-09-17.csv (기존 계획가 포함) | HOLD_VENDOR_REPLY | 판정 보류
BASE | S06 | 구조 | 30시리즈 직각 브래킷 | DCB3025 | 8 | 8 | EA | 나비엠알오 | K56842696 | 660 | 5280 | VAT포함 화면가 | 재고 확인 | ORDER_BASE | 동등 규격 허용 | CAD 수량 PASS | https://www.navimro.com/p/K56842696/ | 상부 내부 코너 8곳 | 2026-09-17 | 기존 9/17 BOM 유지; 국내재고·출하 재확인 | procurement/reve_final_order_bom_2026-09-17.csv (기존 계획가 포함) | HOLD_VENDOR_REPLY | 판정 보류
BASE | M01 | 구동 | 엔코더 리니어 액추에이터 | LM4075OE-1075, DC24V, stroke 100 mm, encoder 5V/6ppr, 10 mm/s, 750 N | 3 | 3 | EA | 모터뱅크 | 1000035578 / 24V·100mm·5V | 126500 | 379500 | 2026-09-17 상세페이지 VAT포함 | 주문제작 7~14일 | ORDER_EXACT_OPTION | 대체 금지 | 27자세/핀거리 PASS | https://www.motorbank.kr/goods/goods_view.php?goodsNo=1000035578 | 세 대 모두 24V·100mm·5V 옵션. 내장 리미트만 사용 | 2026-09-17 | 기존 9/17 BOM 유지; 국내재고·출하 재확인 | procurement/reve_final_order_bom_2026-09-17.csv (기존 계획가 포함) | HOLD_VENDOR_REPLY | 판정 보류
BASE | M02 | 구동 | 하부 피벗 브래킷 | LMB-10, W26/내폭20/L56/H44/핀H36/홀피치36/t3/Ø6.2 | 3 | 3 | SET | 모터뱅크 | 1000007655 / LMB-10 | 4400 | 13200 | 2026-09-17 상세페이지 VAT포함 | 결제 직전 확인 | ORDER_EXACT_ITEM | 대체 금지 | 공개도면/CAD 반영 | https://www.motorbank.kr/goods/goods_view.php?goodsNo=1000007655 | 상세사진의 브래킷·핀·R클립 구성 수령 시 대조 | 2026-09-17 | 기존 9/17 BOM 유지; 국내재고·출하 재확인 | procurement/reve_final_order_bom_2026-09-17.csv (기존 계획가 포함) | HOLD_VENDOR_REPLY | 판정 보류
BASE | M03 | 구동 | 상부 로드엔드 | TRUSCO PHS6, M6 female, bore6, angle13°, total width20, center30, height40, 2개/팩 | 4 | 2 | PK_2 | 한국미스미 | 280-7599 / PHS6 | 14368 | 28736 | 2026-09-17 VAT포함 판매가 | 1일 출하 표시 | ORDER_EXACT_ITEM | 대체 금지 | 보수외곽 27자세 PASS | https://kr.misumi-ec.com/vona2/detail/221005504380/?HissuCode=PHS6 | 3개 사용+1개 예비. 2팩 주문 | 2026-09-17 | 기존 9/17 BOM 유지; 국내재고·출하 재확인 | procurement/reve_final_order_bom_2026-09-17.csv (기존 계획가 포함) | HOLD_VENDOR_REPLY | 판정 보류
BASE | C01 | 가공 | A1 하부 어댑터 | A6061-T6, 120×70×8 mm, A1 Rev E 홀배치 | 1 | 1 | EA | 한국미스미 | A1_LMB_RADIAL_ADAPTER_REVE_120x70x8 | 50000 | 50000 | meviy 계획가/STEP 견적 필요 | 견적 후 약 5~10영업일 | QUOTE_BEFORE_ORDER | 도면 동등 가공 허용 | Rev E 형상 PASS | https://meviy.misumi-ec.com/ko-kr/ | 공급처 인터페이스 STEP로 견적. LMB M8 탭 2개 포함 | 2026-09-17 | 기존 9/17 BOM 유지; 국내재고·출하 재확인 | procurement/reve_final_order_bom_2026-09-17.csv (기존 계획가 포함) | HOLD_VENDOR_REPLY | 판정 보류
BASE | C02 | 가공 | A2 하부 어댑터 | A6061-T6, 120×70×8 mm, A2 Rev E 홀배치 | 1 | 1 | EA | 한국미스미 | A2_LMB_RADIAL_ADAPTER_REVE_120x70x8 | 50000 | 50000 | meviy 계획가/STEP 견적 필요 | 견적 후 약 5~10영업일 | QUOTE_BEFORE_ORDER | 도면 동등 가공 허용 | Rev E 형상 PASS | https://meviy.misumi-ec.com/ko-kr/ | 공급처 인터페이스 STEP로 견적. LMB M8 탭 2개 포함 | 2026-09-17 | 기존 9/17 BOM 유지; 국내재고·출하 재확인 | procurement/reve_final_order_bom_2026-09-17.csv (기존 계획가 포함) | HOLD_VENDOR_REPLY | 판정 보류
BASE | C03 | 가공 | A3 하부 어댑터 | A6061-T6, 120×70×8 mm, A3 Rev E 비대칭 홀배치 | 1 | 1 | EA | 한국미스미 | A3_LMB_RADIAL_ADAPTER_REVE_120x70x8 | 50000 | 50000 | meviy 계획가/STEP 견적 필요 | 견적 후 약 5~10영업일 | QUOTE_BEFORE_ORDER | 도면 동등 가공 허용 | Rev E 형상 PASS | https://meviy.misumi-ec.com/ko-kr/ | A3 비대칭 체결 위치 유지. 임의 대칭화 금지 | 2026-09-17 | 기존 9/17 BOM 유지; 국내재고·출하 재확인 | procurement/reve_final_order_bom_2026-09-17.csv (기존 계획가 포함) | HOLD_VENDOR_REPLY | 판정 보류
BASE | F01 | 체결 | M8×16 육각렌치볼트 | SCM435 10.9, 완전나사, 36개/팩 | 22 | 1 | PK_36 | 나비엠알오 | K53536280 | 7579 | 7579 | VAT포함 화면가 | 재고 확인 | ORDER_BASE | 동등 규격 허용 | 수량 대조 PASS | https://www.navimro.com/p/K53536280/ | 4035 브래킷 16+LMB 6 | 2026-09-17 | 기존 9/17 BOM 유지; 국내재고·출하 재확인 | procurement/reve_final_order_bom_2026-09-17.csv (기존 계획가 포함) | HOLD_VENDOR_REPLY | 판정 보류
BASE | F02 | 체결 | M6×15 육각렌치볼트 | SCM435 10.9, 완전나사, 57개/팩 | 16 | 1 | PK_57 | 나비엠알오 | K53536246 | 6039 | 6039 | VAT포함 화면가 | 재고 확인 | ORDER_BASE | 동등 규격 허용 | 수량 대조 PASS | https://www.navimro.com/p/K53536246/ | 상부 DCB3025 브래킷 16. 스토퍼용 수량 제외 | 2026-09-17 | 기존 9/17 BOM 유지; 국내재고·출하 재확인 | procurement/reve_final_order_bom_2026-09-17.csv (기존 계획가 포함) | HOLD_VENDOR_REPLY | 판정 보류
BASE | F03 | 체결 | M8×20 육각렌치볼트 | SCM435 10.9, 완전나사, 34개/팩 | 6 | 1 | PK_34 | 나비엠알오 | K53536553 | 7359 | 7359 | VAT포함 화면가 | 재고 확인 | ORDER_BASE | 동등 규격 허용 | 수량 대조 PASS | https://www.navimro.com/p/K53536553/ | 하부 어댑터-4040, 축당 2개 | 2026-09-17 | 기존 9/17 BOM 유지; 국내재고·출하 재확인 | procurement/reve_final_order_bom_2026-09-17.csv (기존 계획가 포함) | HOLD_VENDOR_REPLY | 판정 보류
BASE | F04 | 체결 | M8 평와셔 | SUS304, 8.5×17×1, 100개/팩 | 6 | 1 | PK_100 | 나비엠알오 | K06130485 | 5049 | 5049 | VAT포함 화면가 | 재고 확인 | ORDER_BASE | 동등 규격 허용 | 수량 대조 PASS | https://www.navimro.com/p/K06130485/ | LMB 체결부 | 2026-09-17 | 기존 9/17 BOM 유지; 국내재고·출하 재확인 | procurement/reve_final_order_bom_2026-09-17.csv (기존 계획가 포함) | HOLD_VENDOR_REPLY | 판정 보류
BASE | F05 | 체결 | M8 스프링와셔 | SUS304, 8.4×14×2 | 6 | 6 | EA | 나비엠알오 | K15785747 | 440 | 2640 | VAT포함 화면가 | 재고 확인 | ORDER_BASE | 동등 규격 허용 | 수량 대조 PASS | https://www.navimro.com/p/K15785747/ | LMB 축당 2개 | 2026-09-17 | 기존 9/17 BOM 유지; 국내재고·출하 재확인 | procurement/reve_final_order_bom_2026-09-17.csv (기존 계획가 포함) | HOLD_VENDOR_REPLY | 판정 보류
BASE | F06 | 체결 | 40시리즈 M8 스프링너트 | SP408, 100개/팩 | 23 | 1 | PK_100 | 나비엠알오 | K14671419 | 25289 | 25289 | VAT포함 화면가 | 재고 확인 | ORDER_BASE | 동등 규격 허용 | 수량 대조 PASS | https://www.navimro.com/p/K14671419/ | 4035 16+어댑터 6. 스토퍼 수량 제외; DG60103 측정용 홀더 1개용 M8 너트 추가 사용(100개 팩 내). | 2026-09-17 | 기존 9/17 BOM 유지; 국내재고·출하 재확인 | procurement/reve_final_order_bom_2026-09-17.csv (기존 계획가 포함) | HOLD_VENDOR_REPLY | 판정 보류
BASE | F07 | 체결 | 30시리즈 M6 스프링너트 | SP306, 100개/팩 | 20 | 1 | PK_100 | 나비엠알오 | K14671215 | 25289 | 25289 | VAT포함 화면가 | 재고 확인 | ORDER_BASE | 동등 규격 허용 | 수량 대조 PASS | https://www.navimro.com/p/K14671215/ | DCB3025 16+PHS6 스터드 3+예비 1 | 2026-09-17 | 기존 9/17 BOM 유지; 국내재고·출하 재확인 | procurement/reve_final_order_bom_2026-09-17.csv (기존 계획가 포함) | HOLD_VENDOR_REPLY | 판정 보류
BASE | F08A | 체결 | M6×50 상부 피벗 볼트 | 부분나사, 10개/팩 | 3 | 1 | PK_10 | 나비엠알오 | K53672105 | 3410 | 3410 | 화면가 | 재고 확인 | ORDER_BOTH_LENGTHS | 동등 규격 허용 | 실물 적층 확인 필요 | https://www.navimro.com/p/K53672105/ | M6×55와 함께 주문 후 실측 적합 길이 선택 | 2026-09-17 | 기존 9/17 BOM 유지; 국내재고·출하 재확인 | procurement/reve_final_order_bom_2026-09-17.csv (기존 계획가 포함) | HOLD_VENDOR_REPLY | 판정 보류
BASE | F08B | 체결 | M6×55 상부 피벗 볼트 | SUS304, 완전나사, 10개/팩 | 3 | 1 | PK_10 | 나비엠알오 | K02037018 | 3289 | 3289 | 2026-09-17 검색 VAT포함가 | 약 2영업일 표시 | ORDER_BOTH_LENGTHS | 동등 규격 허용 | 실물 적층 확인 필요 | https://www.navimro.com/g/171431/ | M6×50와 함께 주문. 긴 경우 억지 체결 금지 | 2026-09-17 | 기존 9/17 BOM 유지; 국내재고·출하 재확인 | procurement/reve_final_order_bom_2026-09-17.csv (기존 계획가 포함) | HOLD_VENDOR_REPLY | 판정 보류
BASE | F09 | 체결 | 0.5 mm 심링 | CIMR6-12-0.5, ID6/OD12/t0.5 | 9 | 12 | EA | 한국미스미 | CIMR6-12-0.5 | 1000 | 12000 | 계획가/결제화면 재확인 | 3일 수준 예상 | CHECKOUT_PRICE | 동등 치수 허용 | 1.5 mm/축 CAD PASS | https://kr.misumi-ec.com/vona2/detail/110302677870/?HissuCode=CIMR6-12-0.5 | 축당 3장=1.5 mm, 총9장 사용+3장 예비 | 2026-09-17 | 기존 9/17 BOM 유지; 국내재고·출하 재확인 | procurement/reve_final_order_bom_2026-09-17.csv (기존 계획가 포함) | HOLD_VENDOR_REPLY | 판정 보류
BASE | F10 | 체결 | M6 나일론 인서트 너트 | SUS304, 100개/팩 | 3 | 1 | PK_100 | 나비엠알오 | K14536539 | 8789 | 8789 | VAT포함 화면가 | 재고 확인 | ORDER_BASE | 동등 규격 허용 | 조립품 | https://www.navimro.com/p/K14536539/ | 상부 피벗 볼트 풀림방지 | 2026-09-17 | 기존 9/17 BOM 유지; 국내재고·출하 재확인 | procurement/reve_final_order_bom_2026-09-17.csv (기존 계획가 포함) | HOLD_VENDOR_REPLY | 판정 보류
BASE | F11 | 체결 | M6×20 무두렌치 스터드 | 6×20, 10개/팩 | 4 | 1 | PK_10 | 나비엠알오 | K54185516 | 3509 | 3509 | 2026-09-17 검색 화면가/결제 재확인 | 약 7~9영업일 | ORDER_STUD_SOLUTION | 동등 규격 허용 | 무가공 조립안 | https://www.navimro.com/g/1859033/ | PHS6-SP306 연결 3세트+예비1. 1000개입 TB306은 제외 | 2026-09-17 | 기존 9/17 BOM 유지; 국내재고·출하 재확인 | procurement/reve_final_order_bom_2026-09-17.csv (기존 계획가 포함) | HOLD_VENDOR_REPLY | 판정 보류
BASE | F12 | 체결 | M6 잼너트 | SCM435 니켈, 100개/팩 | 8 | 1 | PK_100 | 나비엠알오 | K14532615 | 4169 | 4169 | VAT포함 화면가 | 재고 확인 | ORDER_BASE | 동등 규격 허용 | 무가공 조립안 | https://www.navimro.com/p/K14532615/ | 스터드 4세트×양단 잠금 2개 | 2026-09-17 | 기존 9/17 BOM 유지; 국내재고·출하 재확인 | procurement/reve_final_order_bom_2026-09-17.csv (기존 계획가 포함) | HOLD_VENDOR_REPLY | 판정 보류
BASE | F17 | 체결 | 중강도 나사고정제 | LOCTITE 243, 10 ml | 1 | 1 | EA | 나비엠알오 | K64647607 | 9889 | 9889 | VAT포함 화면가 | 재고 확인 | ORDER_BASE | 동등품 허용 | 조립용 | https://www.navimro.com/p/K64647607/ | 비조정 체결부에만 소량 사용 | 2026-09-17 | 기존 9/17 BOM 유지; 국내재고·출하 재확인 | procurement/reve_final_order_bom_2026-09-17.csv (기존 계획가 포함) | HOLD_VENDOR_REPLY | 판정 보류
BASE | F18 | 체결 | M4×25 더블샘스볼트 | 니켈도금, 평와셔+스프링와셔, 100개/팩 | 20 | 1 | PK_100 | 나비엠알오 | K14364804 | 18139 | 18139 | VAT포함 화면가 | 재고 확인 | ORDER_BASE | 동등 규격 허용 | 전장함 장착용 | https://www.navimro.com/p/K14364804/ | PSU/DIN레일/보드 장착. 길면 짧은 동등품 사용 | 2026-09-17 | 기존 9/17 BOM 유지; 국내재고·출하 재확인 | procurement/reve_final_order_bom_2026-09-17.csv (기존 계획가 포함) | HOLD_VENDOR_REPLY | 판정 보류
BASE | F19 | 체결 | M4 육각너트 | SUS304, 50개/팩 | 20 | 1 | PK_50 | 나비엠알오 | K06130054 | 1529 | 1529 | VAT포함 화면가 | 재고 확인 | ORDER_BASE | 동등 규격 허용 | 전장함 장착용 | https://www.navimro.com/p/K06130054/ | F18과 조합 | 2026-09-17 | 기존 9/17 BOM 유지; 국내재고·출하 재확인 | procurement/reve_final_order_bom_2026-09-17.csv (기존 계획가 포함) | HOLD_VENDOR_REPLY | 판정 보류
BASE | E04 | 전장 | 24 V 30 A급 모터 전원공급기 (SKU 보류) | DC 24 V, 연속 30 A 이상, 720 W 이상; 정격·돌입·접지·보호 확인 필요 | 1 | 1 | EA | 국내 SKU 미선정 | HOLD_SMPS_30A_SKU | 0 | 0 | 비가격 placeholder; 국내 SKU·가격·재고·카드결제 미확정 | 재고 확인 | HOLD_SMPS_30A_SKU | 동일 정격 허용 | 3×7.5 A provisional peak×1.25=28.125 A. 24 V 30 A급은 선정 기준일 뿐 구매 품목 아님. | https://www.devicemart.co.kr/goods/view?no=13231965 | 기존 LRS-350-24(14.6 A)는 현 3축 전동 구동 PSU로 사용 금지. 30 A급 국내 SKU와 단락/돌입/접지/방열 자료 확인 전 주문·모터전원 인가 금지. | 2026-09-17 | 국내 공급처·카드결제·재고·납기 미확정 | verification/reve_z15_electrical_gate_2026-09-20.md; HOLD_SMPS_30A_SKU | HOLD_VENDOR_REPLY | 판정 보류
BASE | E06 | 전장 | ABS 전장함 | SL902, 400×500×155 mm | 1 | 1 | EA | 나비엠알오 | K07636024 | 27489 | 27489 | VAT포함 화면가 | 재고 확인 | ORDER_BASE | 동등 크기 허용 | 기존 부품 유지 / 새 제어계 배치·DC 차단·배선 Task3 재검토 | https://www.navimro.com/p/K07636024/ | 실부품 배치 후 글랜드·버튼 홀 가공 | 2026-09-17 | 기존 9/17 BOM 유지; 국내재고·출하 재확인 | procurement/reve_final_order_bom_2026-09-17.csv (기존 계획가 포함) | HOLD_VENDOR_REPLY | 판정 보류
BASE | E07 | 전장 | 접지 전원코드 | DYP-G15B, 2 m, 1.5sq×3C | 1 | 1 | EA | 나비엠알오 | K08345728 | 4389 | 4389 | VAT포함 화면가 | 재고 확인 | ORDER_BASE | 동등 정격 허용 | AC 입력 | https://www.navimro.com/p/K08345728/ | PE를 PSU 섀시에 직접 연결 | 2026-09-17 | 기존 9/17 BOM 유지; 국내재고·출하 재확인 | procurement/reve_final_order_bom_2026-09-17.csv (기존 계획가 포함) | HOLD_VENDOR_REPLY | 판정 보류
BASE | E08 | 전장 | 2극 배선용 차단기 | ABE32b, 2P2E, 10 A | 1 | 1 | EA | 나비엠알오 | K04115335 | 23089 | 23089 | VAT포함 화면가 | 재고 확인 | ORDER_BASE | 동등 정격 허용 | 벤치 차단 | https://www.navimro.com/p/K04115335/ | 접근 가능한 주전원 차단. 안전등급 주장 안 함 | 2026-09-17 | 기존 9/17 BOM 유지; 국내재고·출하 재확인 | procurement/reve_final_order_bom_2026-09-17.csv (기존 계획가 포함) | HOLD_VENDOR_REPLY | 판정 보류
BASE | E09A | 전장 | ATO 퓨즈홀더 | SZH-FU005, 방수 인라인 | 4 | 4 | EA | 디바이스마트 | 12170196 / SZH-FU005 | 1870 | 7480 | VAT포함 화면가 | 재고 확인 | ORDER_BASE | 동등품 허용 | 축3+제어1 | https://www.devicemart.co.kr/goods/view?no=12170196 | 24V 분기 4개 | 2026-09-17 | 기존 9/17 BOM 유지; 국내재고·출하 재확인 | procurement/reve_final_order_bom_2026-09-17.csv (기존 계획가 포함) | HOLD_VENDOR_REPLY | 판정 보류
BASE | E09B | 전장 | ATO 블레이드 퓨즈 5 A | 32 VDC, 최소주문 10개 | 3 | 10 | EA | 디바이스마트 | 11509 / ATO-5A | 110 | 1100 | VAT포함 화면가 | 재고 확인 | ORDER_BASE | 동등 정격 허용 | 축별 보호 | https://www.devicemart.co.kr/goods/view?no=11509 | 실측 전 임의 증용량 금지 | 2026-09-17 | 기존 9/17 BOM 유지; 국내재고·출하 재확인 | procurement/reve_final_order_bom_2026-09-17.csv (기존 계획가 포함) | HOLD_VENDOR_REPLY | 판정 보류
BASE | E09C | 전장 | 24 V 제어 분기 퓨즈 (정격 보류) | HOLD_CONTROL_FUSE_RATING; 기존 1 A 제품은 발주 대상 아님 | 1 | 3 | EA | 국내 SKU 미선정 | HOLD_CONTROL_FUSE_RATING | 0 | 0 | 비가격 placeholder; 분기 부하·전선·홀더 정격 확인 전 미선정 | 재고 확인 | HOLD_CONTROL_FUSE_RATING | 동등 정격 허용 | Portenta·HWT905·SG01 분기 최악전류와 퓨즈홀더 정격을 확인 후 선정. | https://www.devicemart.co.kr/goods/view?no=16020344 | 기존 1 A 규격을 유지하거나 주문하지 않는다. HMI/KC522 제거 후 실제 제어부 구성 기준으로 재산정. | 2026-09-17 | 국내 SKU·재고·카드결제 미확정 | verification/reve_z15_electrical_gate_2026-09-20.md; 기존 1 A 주장 폐기 | HOLD_VENDOR_REPLY | 판정 보류
BASE | E10 | 전장 | 비상정지/STOP 스위치 | KGAUTO KGE-C4R2R, push-lock/turn-reset, 2a2b, 적색 | 1 | 1 | EA | 디바이스마트 | 10895022 / KGE-C4R2R | 7260 | 7260 | 2026-09-17 VAT포함 판매가 | 약 2주 | ORDER_EXACT_ITEM | 동등 2NC 이상 허용 | 하드웨어 STOP | https://www.devicemart.co.kr/goods/view?no=10895022 | NC 접점으로 릴레이 코일 차단. 안전등급 주장 안 함 | 2026-09-17 | 기존 9/17 BOM 유지; 국내재고·출하 재확인 | procurement/reve_final_order_bom_2026-09-17.csv (기존 계획가 포함) | HOLD_VENDOR_REPLY | 판정 보류
BASE | E11 | 전장 | 모터전력 차단 릴레이 | Omron LY4-D DC24, 4PDT, 다이오드 내장 | 1 | 1 | EA | 디바이스마트 | 8822862 / LY4-D DC24 | 65846 | 65846 | VAT포함 화면가 | 4~5영업일 | ORDER_EXACT_ITEM | 대체 시 DC유도부하 정격 검토 | 기존 부품 유지 / 새 제어계 배치·DC 차단·배선 Task3 재검토 | https://www.devicemart.co.kr/goods/view?no=8822862 | 3접점으로 3축 +24V 분리 차단, 1접점 자기유지 | 2026-09-17 | 기존 9/17 BOM 유지; 국내재고·출하 재확인 | procurement/reve_final_order_bom_2026-09-17.csv (기존 계획가 포함) | HOLD_VENDOR_REPLY | 판정 보류
BASE | E12 | 전장 | 릴레이 소켓 | Omron PTF14A, DIN rail/나사단자 | 1 | 1 | EA | 디바이스마트 | 8831641 / PTF14A | 36443 | 36443 | 2026-09-17 VAT포함 판매가 | 4~5영업일 | ORDER_EXACT_ITEM | LY4-D 호환품만 허용 | 기존 부품 유지 / 새 제어계 배치·DC 차단·배선 Task3 재검토 | https://www.devicemart.co.kr/goods/view?no=8831641 | 릴레이 핀 직접 납땜 금지 | 2026-09-17 | 기존 9/17 BOM 유지; 국내재고·출하 재확인 | procurement/reve_final_order_bom_2026-09-17.csv (기존 계획가 포함) | HOLD_VENDOR_REPLY | 판정 보류
BASE | E13 | 전장 | START 순간버튼 | 한영넉스 CRF-F25M1 G, 녹색, 1a1b, 25파이 | 1 | 1 | EA | 디바이스마트 | 10916422 / CRF-F25M1 G | 2860 | 2860 | 2026-09-17 VAT포함 판매가 | 약 3일 | ORDER_EXACT_ITEM | 1NO 순간접점 동등품 허용 | 사용자 시작명령 | https://www.devicemart.co.kr/goods/view?no=10916422 | 시작 명령/릴레이 자기유지 입력 | 2026-09-17 | 기존 9/17 BOM 유지; 국내재고·출하 재확인 | procurement/reve_final_order_bom_2026-09-17.csv (기존 계획가 포함) | HOLD_VENDOR_REPLY | 판정 보류
BASE | E14 | 전장 | 스크루 단자대 | JOTB-20-10, 20A, 10P | 2 | 2 | EA | 나비엠알오 | K02216060 | 2739 | 5478 | VAT포함 화면가 | 재고 확인 | ORDER_BASE | 동등 정격 허용 | AC/SELV 분리 | https://www.navimro.com/p/K02216060/ | AC와 24/5V 단자대를 물리 분리 | 2026-09-17 | 기존 9/17 BOM 유지; 국내재고·출하 재확인 | procurement/reve_final_order_bom_2026-09-17.csv (기존 계획가 포함) | HOLD_VENDOR_REPLY | 판정 보류
BASE | E15 | 전장 | 14AWG 실리콘 전선 세트 | 적/흑/백, 판매구성 길이 확인 | 1 | 1 | SET | 나비엠알오 | K92854706 | 82489 | 82489 | VAT포함 화면가 | 재고 확인 | CHECKOUT_CONTENT | 동등 굵기/색상 허용 | 모터전력 배선 | https://www.navimro.com/p/K92854706/ | 세 축 케이블 길이를 동등하게 구성 | 2026-09-17 | 기존 9/17 BOM 유지; 국내재고·출하 재확인 | procurement/reve_final_order_bom_2026-09-17.csv (기존 계획가 포함) | HOLD_VENDOR_REPLY | 판정 보류
BASE | E16 | 전장 | 24AWG 제어전선 세트 | UL1007, 6색, 총60 m | 1 | 1 | SET | 나비엠알오 | K92843703 | 34089 | 34089 | VAT포함 화면가 | 재고 확인 | ORDER_BASE | 동등품 허용 | 신호선 | https://www.navimro.com/p/K92843703/ | 버튼·접점·단거리 제어배선용 유지. RS485는 별도 차폐 연선 CB01 사용. | 2026-09-17 | 기존 9/17 BOM 유지; 국내재고·출하 재확인 | procurement/reve_final_order_bom_2026-09-17.csv (기존 계획가 포함) | HOLD_VENDOR_REPLY | 판정 보류
BASE | E17 | 전장 | 열수축튜브 키트 | 12종 750 pcs | 1 | 1 | SET | 나비엠알오 | K52569152 | 12089 | 12089 | VAT포함 화면가 | 재고 확인 | ORDER_BASE | 동등품 허용 | 배선마감 | https://www.navimro.com/p/K52569152/ | 접속부 절연과 식별 | 2026-09-17 | 기존 9/17 BOM 유지; 국내재고·출하 재확인 | procurement/reve_final_order_bom_2026-09-17.csv (기존 계획가 포함) | HOLD_VENDOR_REPLY | 판정 보류
BASE | E18 | 전장 | 케이블 글랜드 | PG13.5, 6~12 mm, 10개/팩 | 7 | 1 | PK_10 | 나비엠알오 | K22571959 | 6919 | 6919 | VAT포함 화면가 | 재고 확인 | ORDER_BASE | 동등 규격 허용 | 기존 부품 유지 / 새 제어계 배치·DC 차단·배선 Task3 재검토 | https://www.navimro.com/p/K22571959/ | 모터3+신호3+AC1 | 2026-09-17 | 기존 9/17 BOM 유지; 국내재고·출하 재확인 | procurement/reve_final_order_bom_2026-09-17.csv (기존 계획가 포함) | HOLD_VENDOR_REPLY | 판정 보류
BASE | E19 | 전장 | 페룰 키트 | DY6330, 0.5~2.5sq | 1 | 1 | SET | 나비엠알오 | K92839991 | 43989 | 43989 | VAT포함 화면가 | 재고 확인 | ORDER_BASE | 동등품 허용 | 연선 단자처리 | https://www.navimro.com/p/K92839991/ | 나사단자에 연선 직접 체결 금지 | 2026-09-17 | 기존 9/17 BOM 유지; 국내재고·출하 재확인 | procurement/reve_final_order_bom_2026-09-17.csv (기존 계획가 포함) | HOLD_VENDOR_REPLY | 판정 보류
BASE | E20 | 전장 | 케이블 타이 | J-200 black, 200×4.8, 1000개/팩 | 1 | 1 | PK_1000 | 나비엠알오 | K01415707 | 17039 | 17039 | VAT포함 화면가 | 재고 확인 | ORDER_BASE | 동등품 허용 | 케이블 고정 | https://www.navimro.com/p/K01415707/ | 이동 케이블에는 여유 루프 확보 | 2026-09-17 | 기존 9/17 BOM 유지; 국내재고·출하 재확인 | procurement/reve_final_order_bom_2026-09-17.csv (기존 계획가 포함) | HOLD_VENDOR_REPLY | 판정 보류
BASE | E21 | 전장 | PVC 절연테이프 | 흑색 10 m×19 mm | 3 | 3 | EA | 나비엠알오 | K40799280 | 550 | 1650 | VAT포함 화면가 | 재고 확인 | ORDER_BASE | 동등품 허용 | 배선마감 | https://www.navimro.com/p/K40799280/ | 영구 접속 절연은 열수축 사용 | 2026-09-17 | 기존 9/17 BOM 유지; 국내재고·출하 재확인 | procurement/reve_final_order_bom_2026-09-17.csv (기존 계획가 포함) | HOLD_VENDOR_REPLY | 판정 보류
BASE | E22 | 전장 | 35 mm DIN 레일 | JTRN-4, steel, 1 m | 1 | 1 | EA | 디바이스마트 | 12538843 / JTRN-4-1M | 16720 | 16720 | VAT포함 환산가 | 재고 확인 | ORDER_BASE | 동등 규격 허용 | 기존 부품 유지 / 새 제어계 배치·DC 차단·배선 Task3 재검토 | https://www.devicemart.co.kr/goods/view?no=12538843 | 전장함 배치 후 필요한 길이만 절단/디버링 | 2026-09-17 | 기존 9/17 BOM 유지; 국내재고·출하 재확인 | procurement/reve_final_order_bom_2026-09-17.csv (기존 계획가 포함) | HOLD_VENDOR_REPLY | 판정 보류
BASE | E23 | 전장 | 녹/황 보호접지선 | TFR-GV 2.5sq, m단위 | 3 | 3 | M | 나비엠알오 | K55027039 | 1419 | 4257 | VAT포함 화면가 | 재고 확인 | ORDER_BASE | 색상 대체 금지 | 보호접지 | https://www.navimro.com/p/K55027039/ | PE-PSU 섀시-노출 도전부 연결 | 2026-09-17 | 기존 9/17 BOM 유지; 국내재고·출하 재확인 | procurement/reve_final_order_bom_2026-09-17.csv (기존 계획가 포함) | HOLD_VENDOR_REPLY | 판정 보류
BASE | E24 | 전장 | 절연 압착단자 키트 | 링/포크 단자 150 pcs | 1 | 1 | SET | 나비엠알오 | K92807634 | 7249 | 7249 | VAT포함 화면가 | 재고 확인 | CHECKOUT_SIZE | 동등품 허용 | 전력/접지 단자 | https://www.navimro.com/p/K92807634/ | 1.5~2.5sq 및 M4/M5 포함 여부 확인 | 2026-09-17 | 기존 9/17 BOM 유지; 국내재고·출하 재확인 | procurement/reve_final_order_bom_2026-09-17.csv (기존 계획가 포함) | HOLD_VENDOR_REPLY | 판정 보류
BASE | PC01 | 제어계 | Portenta Machine Control | AKX00032 / 13963538 | 1 | 1 | EA | 디바이스마트 | AKX00032 / 13963538 | 546667 | 546667 | 화면 표시가546667원(사이트 VAT포함 표기); 별도 관세·수입VAT·운임 포함 여부 미확정 | 화면 4~5일 vs 해외약관 평균10~15일 충돌 / 공급처 확정 필요 | HOLD_LANDED_COST | 검토 없이 대체 금지 | 전장 배치·결선 Task3 / 실물 조립 확인 필요 | https://www.devicemart.co.kr/goods/view?no=13963538 | DigiKey 해외조달. 표시가546667원은 최종 도착원가 아님. 약관15만원 이상 관부가세 고객 부담·취소불가. AL01은 계획 충당액이며 실제 관세/수입VAT/운임 견적 필요. | 2026-09-20 | DigiKey 해외조달 / 고객 별도 관부가세 / 재고244 해외연계 | Task1 AKX00032_devicemart_product_page.html: display L9695, terms L11681–11683 | HOLD_VENDOR_REPLY | 판정 보류
BASE | AL01 | 계획충당 | PC01 수입·운임 계획 충당액(주문품 아님) | PC01 화면가×20% 반올림 / 비확정 계획액 | 1 | 1 | ALLOWANCE | PC01 해외조달 비용 충당(수취인 미확정) | PC01 화면가×20% 반올림 / 비확정 계획액 | 109333 | 109333 | 보수적 20% 계획 충당액; VAT포함 판매가/확정 세액/공급처 견적 아님 | PC01 최종 도착원가 회신 전 미확정 | PLANNING_ALLOWANCE_NOT_QUOTE | 검토 없이 대체 금지 | 전장 배치·결선 Task3 / 실물 조립 확인 필요 | https://www.devicemart.co.kr/goods/view?no=13963538 | 546667×20%=109333.4→109333원 계획 충당. 확정 세액 아님; 실제 세율·과세표준·운임 계산 아님. 견적 수령 후 실제 도착원가로 대체하며 추가비용 가능. 장바구니 입력 금지. | 2026-09-20 | 수입 관부가세·운임 불확실성 / 계획 가정 | 판매약관 비용부담 근거: Task1 archive L11681; 20%는 Task2 fix1 보수적 계획 가정 | HOLD_VENDOR_REPLY | 판정 보류
BASE | DC01 | 제어계 | DMC-200 축1 위치제어 드라이버 | DMC-200 / 1000008040 | 1 | 1 | EA | 모터뱅크 | DMC-200 / 1000008040 | 94380 | 94380 | VAT포함 공개 화면가; 결제 전 재확인 | 결제 전 재확인 | HOLD_VENDOR_REPLY | 검토 없이 대체 금지 | 전장 배치·결선 Task3 / 실물 조립 확인 필요 | https://www.motorbank.kr/goods/goods_view.php?goodsNo=1000008040 | 엔코더 레벨·pull-up·5V전류·계수·내장리미트 복귀·0x0E/0x0F·3노드 회신 전 주문 금지. | 2026-09-20 | 국내 판매·출하 조건 재확인 | Task1 supplier matrix / DMC-200_motorbank_product_page.html | HOLD_VENDOR_REPLY | 판정 보류
BASE | DC02 | 제어계 | DMC-200 축2 위치제어 드라이버 | DMC-200 / 1000008040 | 1 | 1 | EA | 모터뱅크 | DMC-200 / 1000008040 | 94380 | 94380 | VAT포함 공개 화면가; 결제 전 재확인 | 결제 전 재확인 | HOLD_VENDOR_REPLY | 검토 없이 대체 금지 | 전장 배치·결선 Task3 / 실물 조립 확인 필요 | https://www.motorbank.kr/goods/goods_view.php?goodsNo=1000008040 | 엔코더 레벨·pull-up·5V전류·계수·내장리미트 복귀·0x0E/0x0F·3노드 회신 전 주문 금지. | 2026-09-20 | 국내 판매·출하 조건 재확인 | Task1 supplier matrix / DMC-200_motorbank_product_page.html | HOLD_VENDOR_REPLY | 판정 보류
BASE | DC03 | 제어계 | DMC-200 축3 위치제어 드라이버 | DMC-200 / 1000008040 | 1 | 1 | EA | 모터뱅크 | DMC-200 / 1000008040 | 94380 | 94380 | VAT포함 공개 화면가; 결제 전 재확인 | 결제 전 재확인 | HOLD_VENDOR_REPLY | 검토 없이 대체 금지 | 전장 배치·결선 Task3 / 실물 조립 확인 필요 | https://www.motorbank.kr/goods/goods_view.php?goodsNo=1000008040 | 엔코더 레벨·pull-up·5V전류·계수·내장리미트 복귀·0x0E/0x0F·3노드 회신 전 주문 금지. | 2026-09-20 | 국내 판매·출하 조건 재확인 | Task1 supplier matrix / DMC-200_motorbank_product_page.html | HOLD_VENDOR_REPLY | 판정 보류
BASE | IS01 | 제어계 | 상부 절대 경사센서 | HWT905-RS485 / 3973625857 / 옵션03(+46200) | 1 | 1 | EA | G마켓 케이일레븐홀딩스 | HWT905-RS485 / 3973625857 / 옵션03(+46200) | 182530 | 182530 | VAT포함 공개 화면가; 결제 전 재확인 | 9/21 출발 표시 / 무료배송 | CHECKOUT_RECONFIRM | 검토 없이 대체 금지 | 전장 배치·결선 Task3 / 실물 조립 확인 필요 | https://item.gmarket.co.kr/Item?goodsCode=3973625857 | RS485형 정확 선택; 9~36V. 각각 고유주소/20Hz 폴링은 입고 검증. MK700 제외. | 2026-09-20 | 국내배송 전용; 수량2 재고 결제 전 재확인 | Task1 HWT905_RS485_gmarket_evidence_2026-09-20.md | HOLD_VENDOR_REPLY | 판정 보류
BASE | IS02 | 제어계 | 하부 절대 경사센서 | HWT905-RS485 / 3973625857 / 옵션03(+46200) | 1 | 1 | EA | G마켓 케이일레븐홀딩스 | HWT905-RS485 / 3973625857 / 옵션03(+46200) | 182530 | 182530 | VAT포함 공개 화면가; 결제 전 재확인 | 9/21 출발 표시 / 무료배송 | CHECKOUT_RECONFIRM | 검토 없이 대체 금지 | 전장 배치·결선 Task3 / 실물 조립 확인 필요 | https://item.gmarket.co.kr/Item?goodsCode=3973625857 | RS485형 정확 선택; 9~36V. 각각 고유주소/20Hz 폴링은 입고 검증. MK700 제외. | 2026-09-20 | 국내배송 전용; 수량2 재고 결제 전 재확인 | Task1 HWT905_RS485_gmarket_evidence_2026-09-20.md | HOLD_VENDOR_REPLY | 판정 보류
BASE | MV01 | 독립검증 | 독립 Z 검증 디지털 인디케이터 | Mitutoyo 543-730B / K56222641 / 50.8mm / Ø8mm stem | 1 | 1 | EA | 나비엠알오 | Mitutoyo 543-730B / K56222641 / 50.8mm / Ø8mm stem | 681989 | 681989 | VAT포함 공개 화면가; 결제 전 재확인 | 9/28 출하 표시 | CHECKOUT_RECONFIRM | 검토 없이 대체 금지 | 전장 배치·결선 Task3 / 실물 조립 확인 필요 | https://www.navimro.com/p/K56222641/ | 정지한 0/25/50mm Z를 독립 측정·사진 보고용. 폐루프 제어 아님. 최소 예압0.2~0.3mm, 측정범위 초과 금지. HOME/기울임 때 분리. | 2026-09-20 | 국내몰 출하일 표시; 원산지 일본 / 창고 재고 재확인 | gauge.html + gauge_official.html; 공식 stem Ø8mm·50.8mm | HOLD_VENDOR_REPLY | 판정 보류
BASE | MV02 | 독립검증 | Ø8mm 측정기 관절 홀더(베이스 없음) | NOGA DG60103 / HT3205(DG-60103) / 456-0157 | 1 | 1 | EA | 툴앤샵 | NOGA DG60103 / HT3205(DG-60103) / 456-0157 | 142670 | 142670 | VAT포함 공개 화면가; 결제 전 재확인 | 재고 유 / 9/21 출고 표시 | CHECKOUT_RECONFIRM | 검토 없이 대체 금지 | 전장 배치·결선 Task3 / 실물 조립 확인 필요 | https://www.toolnshop.kr/view/?goods=11469 | 제조사 Ø6/8/3⁄8 클램프·판매자 M8×1.25 확인. MV01 stem Ø8 호환. F06 여분너트로 4040에 고정; 도달범위·강성·이탈은 실물 확인. YMB-BV 제외. | 2026-09-20 | 국내 툴앤샵 출하 / 카드결제 | noga_official.html + noga_seller.html | HOLD_VENDOR_REPLY | 판정 보류
BASE | SH02 | 배송 | 측정 홀더 배송비 | 툴앤샵 CJ택배 / 50만원 미만 | 1 | 1 | EA | 툴앤샵 | 툴앤샵 CJ택배 / 50만원 미만 | 3000 | 3000 | VAT포함 공개 화면가; 결제 전 재확인 | 결제 전 재확인 | CHECKOUT_RECONFIRM | 검토 없이 대체 금지 | 전장 배치·결선 Task3 / 실물 조립 확인 필요 | https://www.toolnshop.kr/view/?goods=11469 | 홀더142670원 주문에 표시된 배송비 1건. | 2026-09-20 | 국내배송 | noga_seller.html | HOLD_VENDOR_REPLY | 판정 보류
BASE | SG01 | 제어계 | 절연 Ethernet-RS485 게이트웨이 (SKU 보류) | ICP DAS tGW-715i-T | 1 | 1 | EA | 국내 판매처·카드결제 미확인 | ICP DAS tGW-715i-T | 0 | 0 | 비가격 placeholder; SKU·가격·재고·카드결제 미확정 | HOLD_SG01_QUOTE_CARD_STOCK | HOLD_SG01_QUOTE_CARD_STOCK | 검토 없이 대체 금지 | 전장 배치·결선 Task3 / 실물 조립 확인 필요 | HOLD_SG01_QUOTE_CARD_STOCK | Portenta Ethernet↔SG01 TCP 502↔HWT905 RS485 #11/#12 전용 버스. ICP DAS tGW-715i-T는 기술 후보일 뿐 국내 가격·재고·납기·카드결제 증빙 전 주문 금지. | 2026-09-20 | 국내 구매 가능성만 조사됨; 상업 조건 미확인 | verification/reve_z15_electrical_gate_2026-09-20.md; ICP DAS tGW-715i-T datasheet basis | HOLD_VENDOR_REPLY | 판정 보류
BASE | CB01 | 제어계 | 차폐 3쌍 통신 케이블 | 광일전선 UL2919 / 3P×24AWG / 13352 | 6 | 6 | M | 디바이스마트 | 광일전선 UL2919 / 3P×24AWG / 13352 | 3850 | 23100 | VAT포함 공개 화면가; 결제 전 재확인 | 3~4일 준비 | CHECKOUT_RECONFIRM | 검토 없이 대체 금지 | 전장 배치·결선 Task3 / 실물 조립 확인 필요 | https://www.devicemart.co.kr/goods/view?no=13352 | 6m: 짧은 모터버스 약3m+상하센서 약2m+서비스1m 계획. Task3 배치 후 절단. 체인용 아님; 저속 실내 여유루프. 기존 E16은 접점선. | 2026-09-20 | 국내 판매·출하 조건 재확인 | 13352.html / VAT포함3850원·m단위 | HOLD_VENDOR_REPLY | 판정 보류
BASE | RT01 | 제어계 | RS485 종단저항 | 제일전자 1/4W 1% 121F / 120Ω / 1997 | 2 | 10 | EA | 디바이스마트 | 제일전자 1/4W 1% 121F / 120Ω / 1997 | 44 | 440 | VAT포함 공개 화면가; 결제 전 재확인 | 1~2일 준비 | CHECKOUT_RECONFIRM | 검토 없이 대체 금지 | 전장 배치·결선 Task3 / 실물 조립 확인 필요 | https://www.devicemart.co.kr/goods/view?no=1997 | 필요한 버스 끝에만 최대2개 계획. 내장 종단과 중복 금지, Task3 확정. 10개는 최소주문 단위. | 2026-09-20 | 국내 판매·출하 조건 재확인 | resistor.html | HOLD_VENDOR_REPLY | 판정 보류
BASE | CB02 | 제어계 | Portenta-SG01 Ethernet 케이블 | Anyport AP-6UTP-2M(G) / 10932540 | 1 | 1 | EA | 디바이스마트 | Anyport AP-6UTP-2M(G) / 10932540 | 1320 | 1320 | VAT포함 공개 화면가; 결제 전 재확인 | 3~4일 준비 | CHECKOUT_RECONFIRM | 검토 없이 대체 금지 | 전장 배치·결선 Task3 / 실물 조립 확인 필요 | https://www.devicemart.co.kr/goods/view?no=10932540 | Portenta-SG01 고정 2m. SG01 실제 배치·전원·RJ45 여유 확인 전 절단/이동부 사용 금지. | 2026-09-20 | 국내 판매·출하 조건 재확인 | ethernet_web_evidence.md / HTML archive fetch 실패; Task3 HMI-less architecture | HOLD_VENDOR_REPLY | 판정 보류
BASE | CB03 | 제어계 | Portenta 프로그래밍 USB 데이터 케이블 | Coms C3886 / USB-A to Micro-B / 1061716 | 1 | 1 | EA | 디바이스마트 | Coms C3886 / USB-A to Micro-B / 1061716 | 2750 | 2750 | VAT포함 공개 화면가; 결제 전 재확인 | 2~3일 준비 | CHECKOUT_RECONFIRM | 검토 없이 대체 금지 | 전장 배치·결선 Task3 / 실물 조립 확인 필요 | https://www.devicemart.co.kr/goods/view?no=1061716 | Machine Control 외장 포트는 Micro-B(제조사 핀아웃). H7의 USB-C와 혼동 금지. 기존 Mega 포함선 삭제 후 확보. 판매제목1m/설명1.5m 차이 있으나 직결 진단에 충분; USB-A PC 필요. | 2026-09-20 | 국내 판매·출하 조건 재확인 | program_micro_usb.html + Task1 AKX00032-full-pinout.pdf / VAT포함2750원 | HOLD_VENDOR_REPLY | 판정 보류

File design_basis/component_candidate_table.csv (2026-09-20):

group | candidate | source_id | key_specification | selection_status | reason_to_keep_or_reject | next_check
Actuator | Firgelli F-SD-H-450-12V-8in Hall | SRC-ACT-001 | 450 lbf; 8 in stroke; 319/523 mm; 6 mm/s; 5.5 A; 12 V; 25% duty; IP66; Hall feedback | leading low-load PoC candidate | User-confirmed 10 kg payload / 10 kg cart / +/-3 deg baseline force screen passes with about 618 N maximum axial force, but it is still long and slow | Verify purchased drawing, current, backlash, duty, shock margin, homing method, endpoint margin, and bracket package
Actuator body bracket | Firgelli MB21 | SRC-ACT-007 | Fixed-position Super Duty body support; official STEP envelope 50 x 82.854 x 100 mm | LS-01 fixed-datum candidate | Direct body mounting and official STEP provide a traceable packaging datum | Obtain vendor acceptance or test evidence for external stop reaction and impact
Actuator clevis bracket | Firgelli MB17 | SRC-ACT-008 | 8 mm pin; 180 deg pivot; official STEP | reference only | Confirms the vendor clevis mounting ecosystem | Does not replace the required spherical/misalignment joint or prove adapter compatibility
Actuator body bracket | Firgelli MB20 | SRC-ACT-009 | Swiveling body bracket with rubber gasket; official STEP | alternate reference | Could move the body pivot if packaging requires it | Not selected because LS-01 needs a fixed repeatable body datum
Actuator | Ewellix CAHB-10 | SRC-ACT-002 | 1500 N; 50-300 mm stroke; 12/24 V; IP66S; 25% duty | reserve candidate | Good documentation but may be marginal for high eccentric load | Check exact speed/current options and price
Actuator | TiMOTION MA2 | SRC-ACT-003 | 8000 N push; 4000 N pull; 25-1000 mm stroke; Hall/pot options | industrial reserve | Keep only if the simple Firgelli package fails geometry, speed, duty, or test margin | Request quote only after baseline package fails
Actuator | LINAK LA36 | SRC-ACT-004 | 6800 N; 100-1200 mm stroke; IP66 dynamic/IP69K static | industrial reserve | Keep only if the simple Firgelli package fails geometry, speed, duty, or test margin | Request quote only after baseline package fails
Actuator | Thomson Electrak HD | SRC-ACT-005 | 12/24 V; 25% duty variants; IP66 dynamic/IP67/IP69K static | upgrade benchmark | High-end industrial reference | Quote and availability
Actuator | Progressive Automations PA-17 | SRC-ACT-006 | 850/2000 lbf dynamic options; IP65; 25% duty | oversized fallback | Useful if very high force is required | Package, mass, speed, import cost
Latch | DESTACO 323-R | SRC-LAT-001 | 360 lbf maximum holding capacity | candidate | Simple pull-action latch for preload/uplift only; not primary shear and not final SKU | Check latch geometry, secondary lock, latch sensor, preload, and release clearance
Latch | Southco draw latch family | SRC-LAT-002 | Over-center adjustable/heavy-duty draw latch families | reserve candidate | Commercial latch family with many sizes | Select exact SKU and load table
Latch | Elesa+Ganter GN 850 | SRC-LAT-003 | Hook-type toggle clamps; holding capacity by size | reserve candidate | Industrial latch clamp alternative | Select exact size
Latch | Elesa+Ganter GN 850.2 | SRC-LAT-004 | Hook-type toggle clamp with safety hook | safety-feature candidate | Safety hook helps against inadvertent release | Check price and available sizes
Frame | MISUMI HFS8-4040 | SRC-FRM-001 | 40x40; 1.73 kg/m; area 640 mm2; Ix/Iy 10.4e4 mm4 | candidate | Good modular PoC frame candidate; exact procurement code should be separated from profile series | Joint, bracket, bolt, slot and plate stiffness
Frame | Aluminum profile cart receiver rail/subframe | SRC-FRM-001 | T-slot/profile receiver concept; exact 30/40 mm class section TBD; local hard points use separate insert plates | user-preferred concept | Matches user preference for easy fabrication assembly and adjustment without relying on raw profile slots as wear faces | Select exact sourced section, connector type, insert plate layout, and mass budget
Frame | CR-01 two-rail cart receiver kit | SRC-FRM-001 | Two 760 mm HFS8-4040 longitudinal receiver rails; 760 x 560 mm receiver zone; screened mass about 4.50 kg with placeholder hard points | preferred layout candidate | Lighter than the 6.43 kg rectangular subframe reserve and leaves more of the 10 kg empty-cart basis for the rest of the cart | Confirm connector stiffness, insert plates, locator hardware, rest pad adjustment, and latch keeper geometry
Frame | CR-01-H1 local hardpoint set | SRC-FRM-001 | 12 mm locator interface; 8 mm locator insert; 40 x 30 mm rest pad contact; 5 mm latch keeper; two M8-class fasteners per critical hard point; positive stop/dowel/key after alignment | hardpoint seed | Bulk stress screens are low, but repeatability must come from hard points and positive anti-slip features rather than profile-slot friction | Select exact slot nut, backing plate, locator bushing, shim method, latch keeper shape, secondary lock and sensor
Frame | CR-01-H2-B connector topology | SRC-FRM-001 | two M8-class T-slot fasteners per critical hard point for clamp/adjustment; shoulder/key/positive stop final shear path; optional 6 mm or larger dowel; backing plate reserve | preferred topology seed | Friction-only slot fastening passes a placeholder slip screen but is rejected for final locating; positive-stop and dowel stresses are low at the active PoC demand | Select exact slot nut, profile wall bearing, backing plate need, replaceable stop geometry, dowel position, and service access
Frame | CR-01-H3 connector stack rules | SRC-FRM-001 | master locator X/Y fixed; secondary locator Y-only and X released; rest pad Z-only; latch keeper preload/uplift-only; 30-cycle mock-up backing-plate trigger | preferred detail seed | Avoids hidden overconstraint and keeps backing plates conditional on measured shift, torque relaxation, wall marking or preload drift | Select exact slot nut/backing plate, replaceable stop block, dowel position, latch-closed/cart-present sensor bracket and access
Frame | MISUMI GFS8-4040 | SRC-FRM-002 | 2.17 kg/m; Ix/Iy 13.76e4 mm4 | stiffness option | Higher stiffness with modest mass increase | Use if deflection/stiffness fails
Frame | Bosch Rexroth profile system | SRC-FRM-003 | Industrial profile system and accessories | benchmark | Alternative supplier/reference system | Select metric profile data
Frame | MISUMI Korea economy 4040 | SRC-FRM-004 | Domestic economy procurement listing | procurement screen only | May reduce cost | Do not use load-critical economy profile without spec verification
Guide | THK HSR linear guide | SRC-GDE-001 | HSR 15+ dynamic ratings from 10.9 kN upward | high-rigidity candidate | Strong guide option for central constraint | Cost, contamination, packaging
Guide | HIWIN MGN15H | SRC-GDE-002 | Dynamic 6370 N; static 9110 N | compact guide candidate | Compact and strong enough for many guide loads | Misalignment sensitivity
Guide | MISUMI TPCAT tapered locating pin | SRC-GDE-003 | D2/tool steel equivalent; 58-62 HRC | cart locating candidate | Good for repeatable mechanical seating | Contact/shear stress after receiver geometry
Guide | KIPP locating pins/rest pads | SRC-GDE-004 | Locating/rest pad families | alternate supplier | Useful for locating/rest pad design | Select exact part and load data
Joint | MISUMI PHSOSM8 | SRC-JNT-001 | 2.69 kN radial static; 12 deg allowable angle | screened out for primary actuator joint | Fails the current lower actuator joint screen at +/-3 deg when 2 deg angular margin and 2x static load screen are applied | May remain a low-load auxiliary joint only
Joint | THK POS8 | SRC-JNT-002 | 8 mm rod end; CAD/catalog available | candidate | Known supplier alternative | Need load rating before selection
Joint | MISUMI/Minebea HRT8E | SRC-JNT-006 | 26.77 kN radial static; 5.29 kN axial static; 14 deg tilt | leading +/-3 actuator joint candidate | User no longer requires +/-5 deg; HRT8E-style rod end is simpler if the bracket preserves the required articulation | Check local procurement, bracket package, axial load direction and bolt/stud bending
Joint | MISUMI RBLD8 link ball style | SRC-JNT-004 | M8 static load capacity 12500 N; allowable incline angle up to 40 deg in inCAD table | high-angle reserve | Keep as reserve if HRT8E-style rod end packaging loses angular margin | Confirm exact purchasable SKU, holder geometry, bracket clearance, wear and side-load path
Joint | JNT-BR-01-HRT8E preliminary screen | SRC-JNT-006; SRC-STD-004 | centered double-shear: 8 mm lug/pin seed; <=16 mm provisional supported pin span | superseded_preliminary_seed | Superseded after official 23 x 11 mm HRT8E envelope showed the 16 mm gap was too tight at 14 deg | Retain as calculation history only; use the 18 mm detailed CAD seed
Joint | JNT-BR-01-HRT8E detailed CAD | SRC-JNT-006; SRC-STD-004 | official 8 mm bore / 23 mm body / 11 mm eye; 18 mm yoke gap; retained M8 pin envelope | archived after factory-eye review | Serial adapter length conflicts with the current lower-stroke workspace | Retain as design history or reconsider only with changed support geometry
Joint | JNT-CG-01 factory-eye nested gimbal | SRC-ACT-001; SRC-ACT-010 | 8.2 mm factory hole and 20 mm eye OD family reference; 12 mm adjustable mock-up gap; 6 mm plates; opposed M8 trunnions; zero centre offset | preferred measured-mockup seed | Preserves current actuator pin-to-pin kinematics and supplies two orthogonal rotations | Family drawing is not the selected 450 lbf 8-inch drawing; measure purchased eye and pin stack before copying six times
Joint | Ruland single universal joint family | SRC-JNT-005 | Single U-joints up to 45 deg angular misalignment; keyed metric bore options | central Cardan family reference | Suitable component class for yaw-transmitting Cardan geometry by angle only | Do not use as sole yaw-torque path without torque/backlash verification
Joint | Ruland MUS15-8-8-F | SRC-JNT-007 | 8 mm bore; rated torque 15.3 Nm; max angle 45 deg | geometry reference only | Still just below the simplified 16 Nm primary PoC design yaw torque if used alone | Small geometry reference only
Joint | Ruland MUSSK22-12-12-F | SRC-JNT-008 | 12 mm keyed bore; rated torque 39 Nm; peak torque 197 Nm; max angle 45 deg | possible low-load reference only | May satisfy simplified PoC yaw torque numerically, but YAW-A should carry yaw through the keyed guide for simpler constraint control | Use only as a yoke geometry reference unless yaw torque path is redesigned
Joint | Ruland US32-22MM-20MM-F | SRC-JNT-009 | 22/20 mm bore; rated torque 485.8 Nm; peak torque 2429.2 Nm; max angle 45 deg; 50.7 mm OD; 139.7 mm length | oversized reserve Cardan | No longer attractive for the user-confirmed low-load PoC because package/cost/shaft details add complexity | Use only if the keyed guide yaw path fails
Joint | MISUMI BSHS16 ball spline reference | SRC-JNT-010 | No.16 dynamic torque 51 Nm; static torque 93 Nm | low-load reserve concept | Could pass the simplified torque level, but still needs pitch/roll isolation and may add procurement/package complexity | Study only if YAW-A keyed guide becomes too hard to fabricate
Sensor | Adafruit BNO085 breakout | SRC-SEN-001 | Sensor-fusion IMU breakout; 29.50 USD listed; Game Rotation Vector available | candidate | Fast prototype integration; Game Rotation Vector can avoid magnetometer correction jumps but yaw drift remains a test issue | Vibration, drift, mounting, magnetic robustness, and acceptance-error testing
Sensor | Bosch BNO055 | SRC-SEN-002 | 9-axis absolute orientation sensor | not preferred | Manufacturer page notes not recommended for new designs | Avoid unless already stocked
Sensor | TDK ICM-20948 | SRC-SEN-003 | 9-axis IMU with DMP; EOL status | rejected | End-of-life status | Do not design in
Sensor | WitMotion WT901C | SRC-SEN-004 | 0.2 deg tilt accuracy; up to 200 Hz; -40 to 85 C | industrial-style option | Better packaged tilt sensor candidate | Protocol/noise testing
Driver | Cytron MD13S | SRC-DRV-001 | 13 A continuous; 30 A peak 10 s; 6-30 V; single channel | single-channel candidate | Would require three units for three independent actuator channels | Thermal test with actual actuator
Driver | Cytron MD20A | SRC-DRV-002 | 20 A continuous; 60 A peak; 6-30 V; single channel | single-channel candidate | More current margin than MD13S, but still one channel per board | Reverse-voltage protection plan
Driver | Cytron MDD20A | SRC-DRV-004 | 20 A continuous; 6-30 V; two channels | two-channel candidate | Could cover two of the three required independent channels | Pair with one additional single-channel driver or use multi-axis controller
Driver | Pololu G2 24v13 | SRC-DRV-003 | 6.5-40 V; 13 A; current sense/limit; reverse protection | alternate candidate | Useful protection/current sensing | No over-temperature shutoff
Power | Mean Well LRS-350-24 | SRC-PWR-001 | 24 V 14.6 A 350.4 W | 24v candidate only | Not compatible with a 12 V actuator bus unless DC-DC conversion or 24 V actuator variant is used | Resolve actuator bus voltage first
Power | Omron S8VK-G48024 | SRC-PWR-002 | 24 V 20 A 480 W DIN rail | 24v candidate only | Not compatible with a 12 V actuator bus unless DC-DC conversion or 24 V actuator variant is used | Resolve actuator bus voltage first
Power | TDK-Lambda DRF240-24-1 | SRC-PWR-003 | 24 V 10 A 240 W; 15 A peak | 24v candidate only | Likely insufficient for three actuators and not compatible with 12 V bus directly | Resolve actuator bus voltage first
Safety | Omron A22E-M-03 | SRC-SAF-001 | 22 mm; 40 mm head; push-lock turn-reset; 3NC; IP65 | E-stop candidate | Industrial E-stop family | Safety circuit design later
Safety | Omron D4N-4D32 envelope reference | SRC-SAF-002 | IP67; direct opening; roller plunger 9.5 dia x 5; PT 2 mm max; OT 4 mm min | archived static-bench option | Removed from active CAD/BOM by user scope reduction | Reconsider for mobile unattended higher-speed or safety-reviewed operation
Mechanical stop | Ruland MSP-12-FZ | SRC-STP-001 | 12 mm bore; 28 mm OD; 11 mm width; two-piece steel clamp; M4 x 12 screws | LS-01 stop-collar geometry candidate | Easy adjustment and replacement on twin 12 mm rods | Supplier/project push-off and impact acceptance still required
Safety | Schneider Harmony XB4/ZB4 | SRC-SAF-003 | IP66/67/69/69K; -40 to 70 C | alternate control/E-stop family | Strong industrial ecosystem | Select exact SKU
Cart receiver hardware | CR-01-H4-S1 | SRC-FRM-001; SRC-GDE-003; SRC-GDE-004; SRC-LAT-004; SRC-STD-004 | 12 mm removable master bushing and replaceable stop; X-slot/diamond secondary; 40 x 30 mm shim pad; 5 mm keeper + separate mechanical secondary lock | low-load PoC hardware seed | Simple serviceable assembly seed that preserves H3 role separation | Select purchased hardware, fits, torque, stop screws, latch and sensors after mock-up
Central guide | Compact YAW-A Cardan constraint | SRC-GDE-003; SRC-GDE-004; SRC-STD-004 | 120 mm mount envelope; fixed +Y pitch; local +X roll; 12 mm pin seed; +/-7 deg per-axis stops | active compact CAD seed | Retains required X/Y/yaw constraint while keeping three radial actuators visually dominant | Add actual bushings shoulder bolts retention fits and no-contact mock-up evidence
Safety mechanism | Passive telescopic stop cartridge pair | SRC-STD-004 | two below-deck captured-shoulder cartridges; separate electrical switch envelopes | archived_not_preferred | Mechanically screened but rejected after user design feedback because the central package was visually heavy | Retain only in outputs/archive/yaw_a_detailed_2026-08-26
Safety mechanism | LS-01M radial actuator stop collar set | SRC-ACT-001; SRC-STP-001 | twelve mechanical collars on six moving rods; factory internal electrical endpoints; no external D4N package | active static-bench CAD seed | Simple stationary supervised test configuration that keeps an independent mechanical travel path | Verify collar push-off actual endpoints and MB21 reaction before powered test
Actuator | DIHOOL DHLA2000 LA2000-125150 non-flat pin/lug assumption | SRC-ACT-011; SRC-PROC-004; SRC-PROC-023; SRC-PROC-026 | 12 V; 2000 N; 150 mm stroke; 5 mm/s; M8-to-eye accessory assumed; Hall optional at family level | selected NAVIMRO redesign planning baseline | At 185 mm vertical joint separation it permits 270 mm collapsed height and 273.20-385.35 mm workspace with balanced provisional endpoint reserve | Obtain exact supplied accessory both-end interface pivot-center lengths Hall wiring current and matching STEP before fabrication release
Actuator joint | JMC JFT-8R spherical rod end | SRC-PROC-027 | NAVIMRO K02020097; M8x1.25 RH female; 8 mm bore; six total | selected Rev D joint hardware | One spherical bearing at each actuator end supplies the required multi-axis articulation inside a fabricated double-shear yoke | Confirm delivered A2 male/female M8 interface, receipt dimensions, pivot shoulder and full thread engagement
Driver | Cytron MD10C NAVIMRO listing | SRC-PROC-007 | 13 A single-channel brushed DC motor driver | NAVIMRO PoC driver candidate | One independent channel per actuator and ample preliminary current class for the 30 W actuator family | Verify stock actual actuator current thermal margin wiring and branch protection
Frame | NAVIMRO Daeyoung DF 4040-8 cut set | SRC-PROC-010; SRC-PROC-011 | 40 x 40 profile; Rev D 19 cut pieces totaling 12000 mm; DAB4040 angle stock | NAVIMRO single-order frame candidate | Bolted construction and connected 640/660 mm crossmembers support easy local assembly | Freeze revised hole and hardpoint drawings before purchase
Upper deck | NAVIMRO 900 x 800 x 15 PMMA pack | SRC-PROC-012 | Two-sheet pack; supported non-primary deck | NAVIMRO single-order panel candidate | Exact target footprint is listed and one spare sheet avoids a second order | Maintain close profile support and steel load spreaders
Central guide | NAVIMRO twin 12 mm shaft guide | SRC-PROC-014 | 2x 12 mm ground shafts; 4x LMF12UU; 4x SK12 | preferred procurement redesign | Commercial guide hardware reduces custom tube fitting while constraining X Y and yaw | Revise CAD for flange pattern support height alignment and carriage stiffness
Mechanical stop | BOTECO Y710028.VBD12 | SRC-PROC-015 | 12/28/11 mm single-split collar | conditional NAVIMRO stop | Matches the guide-shaft geometry at lower cost than the first two-piece candidate | Obtain axial holding data or proof-test push-off before powered use
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

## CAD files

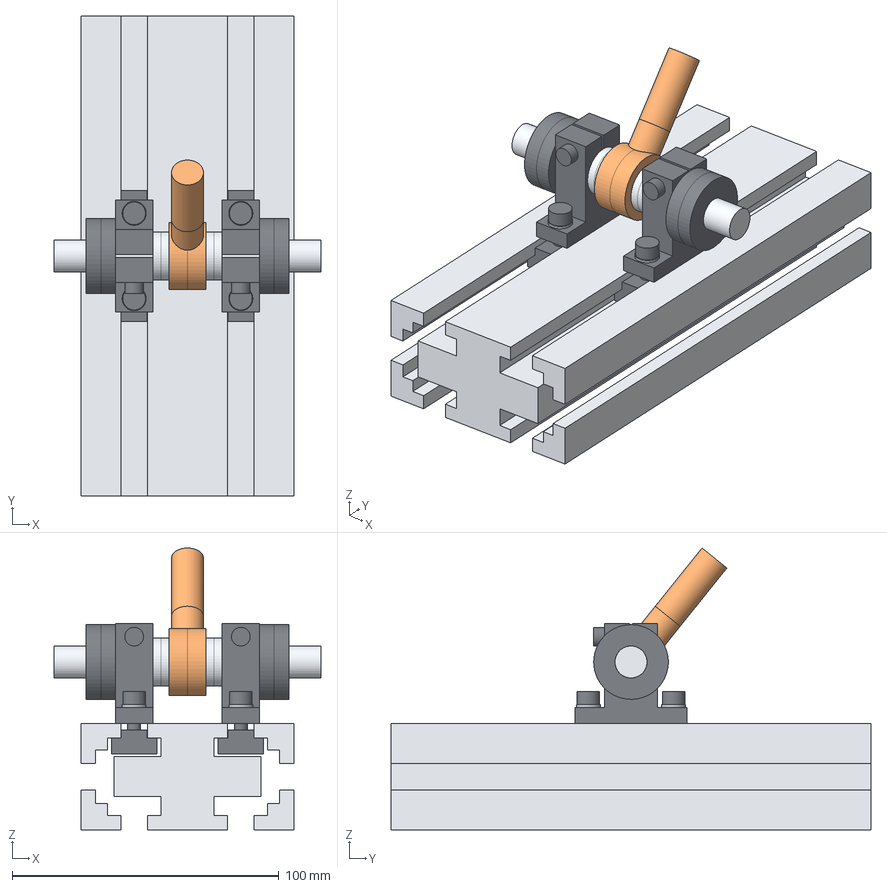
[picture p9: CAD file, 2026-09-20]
outputs/manual_m2r2f2_one_axis/step/A1_LOWER_ASSEMBLED_REVIEW.step
100.0 x 180.0 x 105.7 mm
LOWER_HFS8_4080
BJ761_12011N
L1_SHAT12_L
L1_L_M5X16_1
L1_L_W5_1
L1_L_HNTT8_5_1
L1_L_M5X16_2
L1_L_W5_2
L1_L_HNTT8_5_2
L1_SHAT_CLAMP_HEAD_L
L1_SHIM_STACK_L
L1_MCL12F_L
L1_SHAT12_R
L1_R_M5X16_1
L1_R_W5_1
L1_R_HNTT8_5_1
L1_R_M5X16_2
L1_R_W5_2
L1_R_HNTT8_5_2
L1_SHAT_CLAMP_HEAD_R
L1_SHIM_STACK_R
L1_MCL12F_R
L1_SHAFT12X100

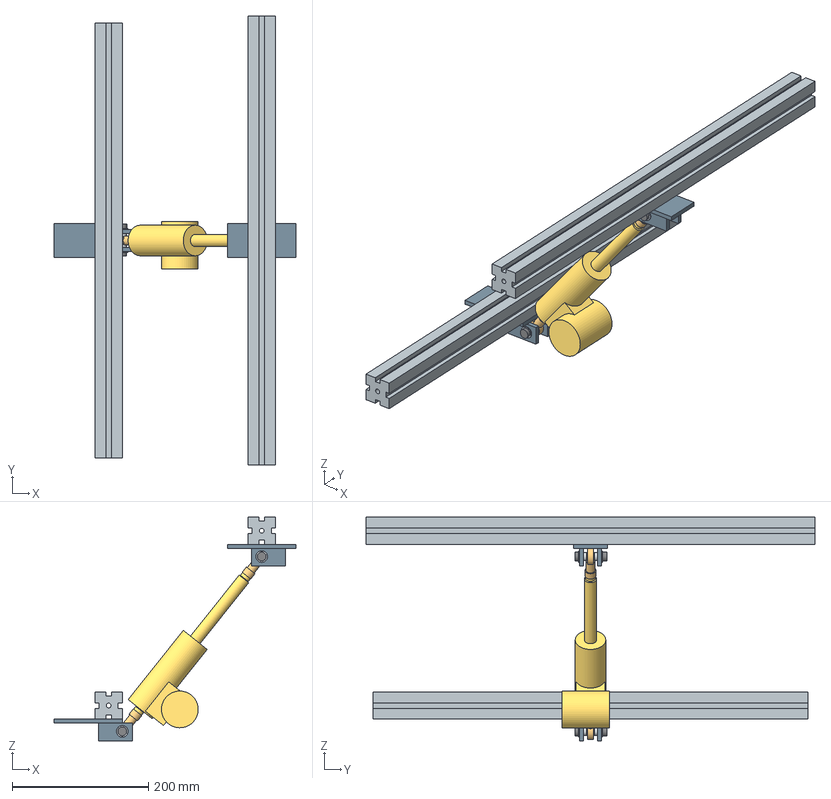
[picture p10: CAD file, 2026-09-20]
outputs/navimro_fusion360_revE/step/ACT1_complete_mounting_cassette_neutral_revE.step
355.0 x 660.0 x 329.0 mm
LWR_actuator_cross
NVR-P04_lower_spreader_1
UPR_end_front
NVR-P03_upper_spreader_1
LA2000_A2_PROVISIONAL_1
ACT1_LOWER_JFT8R
ACT1_LOWER_M8_A2_ADAPTER_PROVISIONAL
ACT1_LOWER_spacer_pair
ACT1_LOWER_pin
ACT1_LOWER_washer_A
ACT1_LOWER_washer_B
ACT1_LOWER_nyloc
ACT1_UPPER_JFT8R
ACT1_UPPER_M8_A2_ADAPTER_PROVISIONAL
ACT1_UPPER_spacer_pair
ACT1_UPPER_pin
ACT1_UPPER_washer_A
ACT1_UPPER_washer_B
ACT1_UPPER_nyloc
ACT1_LOWER_yoke_lug_A
ACT1_UPPER_yoke_lug_A
ACT1_LOWER_yoke_lug_B
ACT1_UPPER_yoke_lug_B

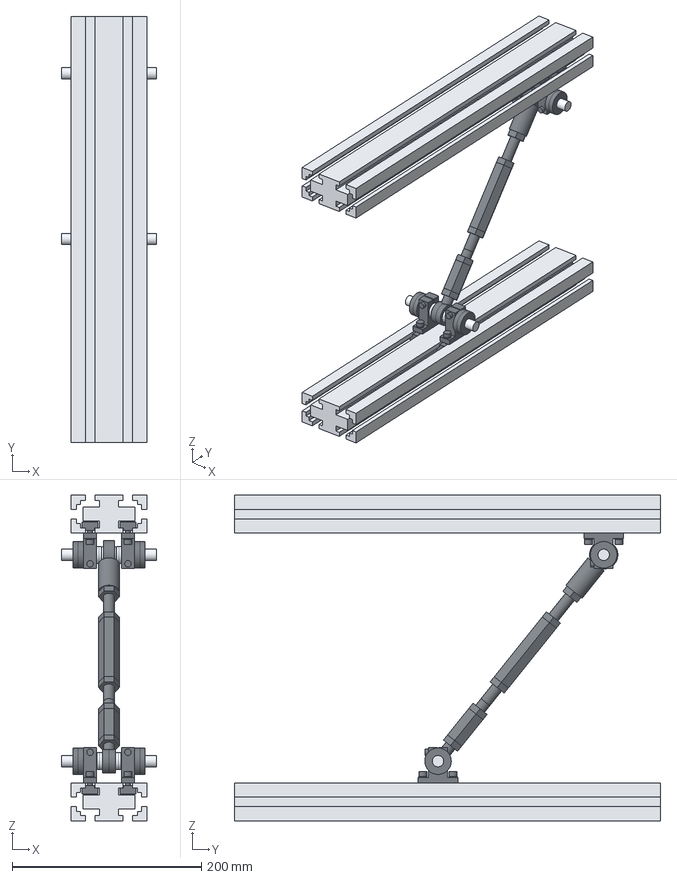
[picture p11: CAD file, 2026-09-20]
outputs/manual_m2r2f2_one_axis/step/A1_COMPLETE_ASSEMBLED_REVIEW.step
100.0 x 450.0 x 344.0 mm
LOWER_FRONT_RAIL
UPPER_FRONT_RAIL
L1_SHAT12_L
L1_L_M5X16_1
L1_L_W5_1
L1_L_HNTT8_5_1
L1_L_M5X16_2
L1_L_W5_2
L1_L_HNTT8_5_2
L1_SHAT_CLAMP_HEAD_L
L1_SHIM_STACK_L
L1_MCL12F_L
L1_SHAT12_R
L1_R_M5X16_1
L1_R_W5_1
L1_R_HNTT8_5_1
L1_R_M5X16_2
L1_R_W5_2
L1_R_HNTT8_5_2
L1_SHAT_CLAMP_HEAD_R
L1_SHIM_STACK_R
L1_MCL12F_R
L1_SHAFT12X100
U1_SHAT12_L
U1_L_M5X16_1
U1_L_W5_1
U1_L_HNTT8_5_1
U1_L_M5X16_2
U1_L_W5_2
U1_L_HNTT8_5_2
U1_SHAT_CLAMP_HEAD_L
U1_SHIM_STACK_L
U1_MCL12F_L
U1_SHAT12_R
U1_R_M5X16_1
U1_R_W5_1
U1_R_HNTT8_5_1
U1_R_M5X16_2
U1_R_W5_2
U1_R_HNTT8_5_2
U1_SHAT_CLAMP_HEAD_R
U1_SHIM_STACK_R
U1_MCL12F_R
U1_SHAFT12X100
A1_TURNBUCKLE
A1_PHS12L_INNER

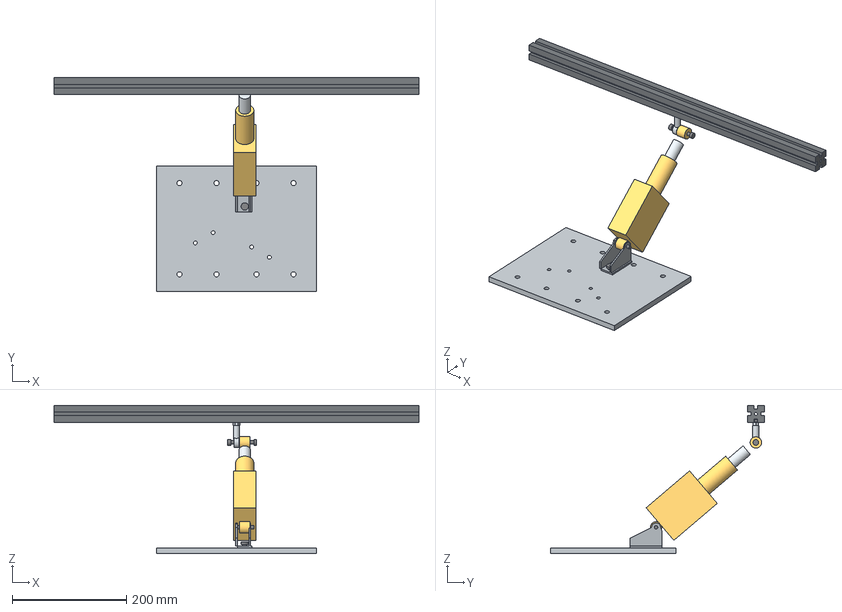
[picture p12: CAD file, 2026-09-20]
outputs/minimal_radial_revC/step/DETAIL_A1_COMPLETE_JOINT_revC.step
640.0 x 375.0 x 260.0 mm
LMB10_A1_2x_M8x16_tapped_hub
lower_hub_plate_280x220x10
LMB10_A1
LMB10_A1_included_pin
upper_cross_A1
PHS6_A1_TB306_M6x20
PHS6_A1_M6x50_joint_bolt
PHS6_A1_outer
PHS6_A1_spherical_inner_ring
LM4075OE_A1_body
LM4075OE_A1_rod
LM4075OE_A1_lower_eye
LM4075OE_A1_upper_eye

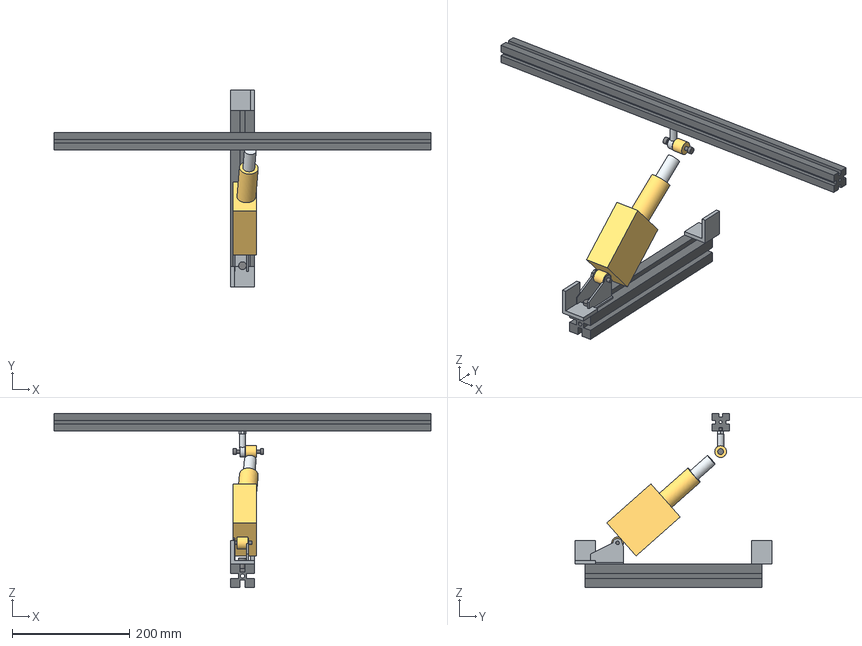
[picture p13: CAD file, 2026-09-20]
outputs/minimal_profile_only_revB/step/ACTUATOR_1_complete_joint_detail_revB.step
640.0 x 335.0 x 296.0 mm
lower_A1_radial_rail
lower_4035_7_A1_inner
lower_4035_8_A1_outer
LMB10_A1
LMB10_A1_included_pin
LMB10_A1_2x_M8x16_SP408
upper_cross_A1
PHS6_A1
PHS6_A1_TB306_M6x20
LM4075OE_A1_body
LM4075OE_A1_rod
LM4075OE_A1_lower_eye
LM4075OE_A1_upper_eye
PHS6_A1_M6x50_joint_bolt

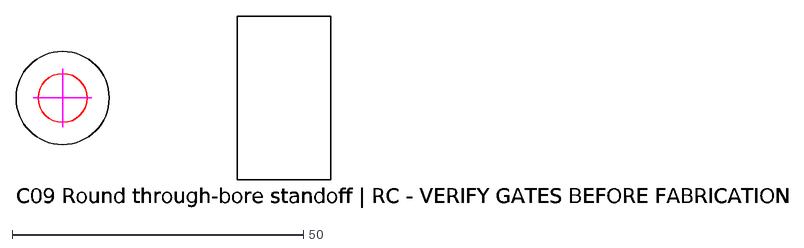
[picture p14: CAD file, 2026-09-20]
fabrication/profile_radial_revE_release_candidate_2026-09-04/C09_ROUND_THROUGH-BORE_STANDOFF.dxf
C09 Round through-bore standoff | RC - VERIFY GATES BEFORE FABRICATION

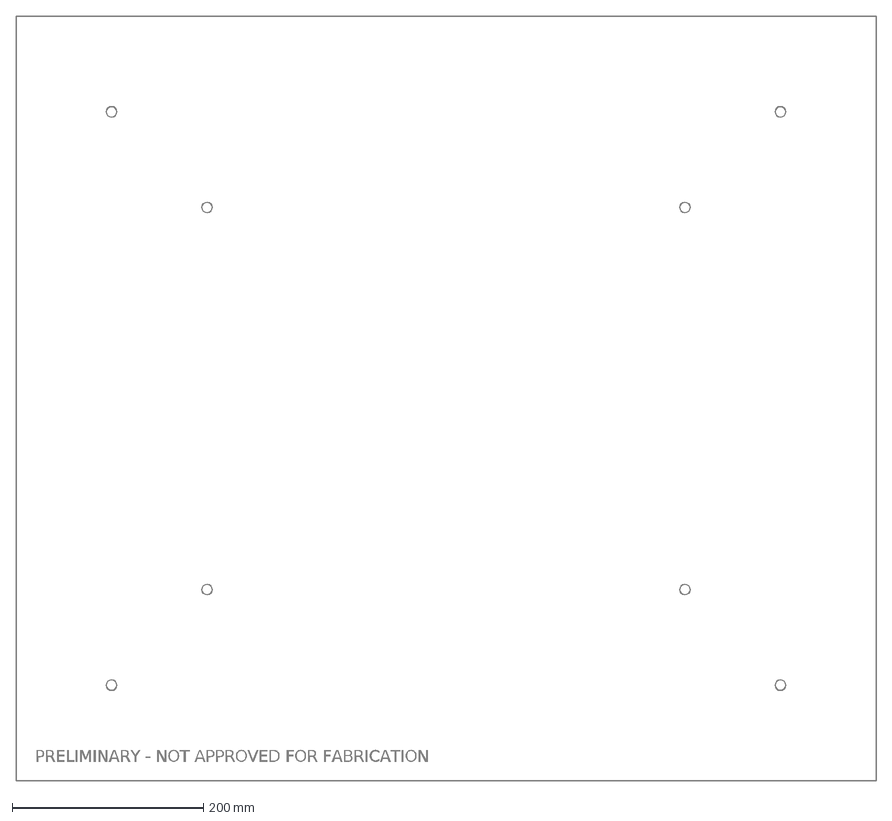
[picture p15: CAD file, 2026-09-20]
outputs/cad/dxf/lower_interface_plate_profile.dxf
PRELIMINARY - NOT APPROVED FOR FABRICATION

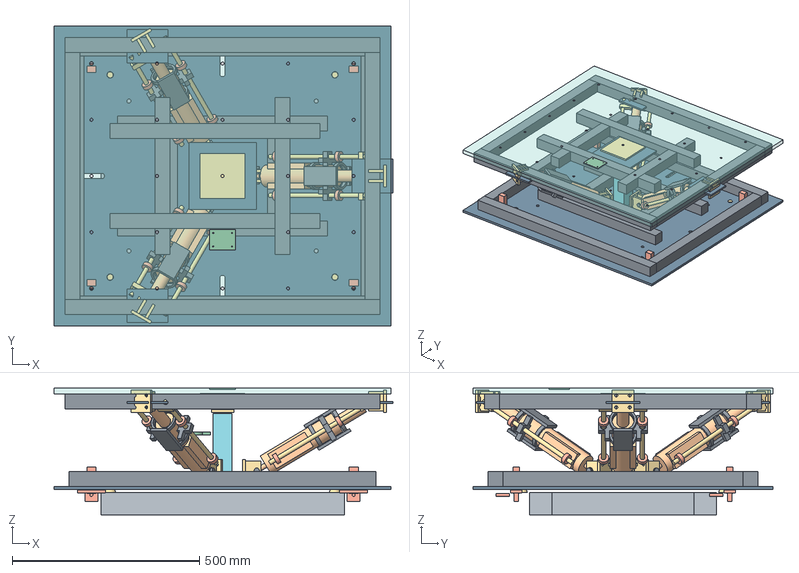
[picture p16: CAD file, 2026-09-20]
outputs/cad/step/leveling_module_collapsed.step
905.0 x 800.0 x 338.0 mm
lower_interface_plate
lower_HFS8_frame
lower_actuator_brackets
lower_actuator_bushings
lower_actuator_misalignment_spacers
lower_actuator_pins_retention
cart_receiver_dummy
cart_guide_receivers
four_mechanical_latches
keyed_guide_outer
keyed_guide_inner
compact_cardan_lower
compact_cardan_cross
compact_cardan_upper
compact_cardan_angle_stops
upper_HFS8_frame
upper_acrylic_panel
upper_load_spreaders
upper_radial_clevises
upper_actuator_bushings
upper_actuator_misalignment_spacers
upper_actuator_pins_retention
imu_bracket
cable_guide
actuator_A1
actuator_A1_limit_fixed_carrier
actuator_A1_limit_guide_bushings
actuator_A1_limit_moving_striker
actuator_A1_external_mechanical_stops
actuator_A2
actuator_A2_limit_fixed_carrier
actuator_A2_limit_guide_bushings
actuator_A2_limit_moving_striker
actuator_A2_external_mechanical_stops
actuator_A3
actuator_A3_limit_fixed_carrier
actuator_A3_limit_guide_bushings
actuator_A3_limit_moving_striker
actuator_A3_external_mechanical_stops

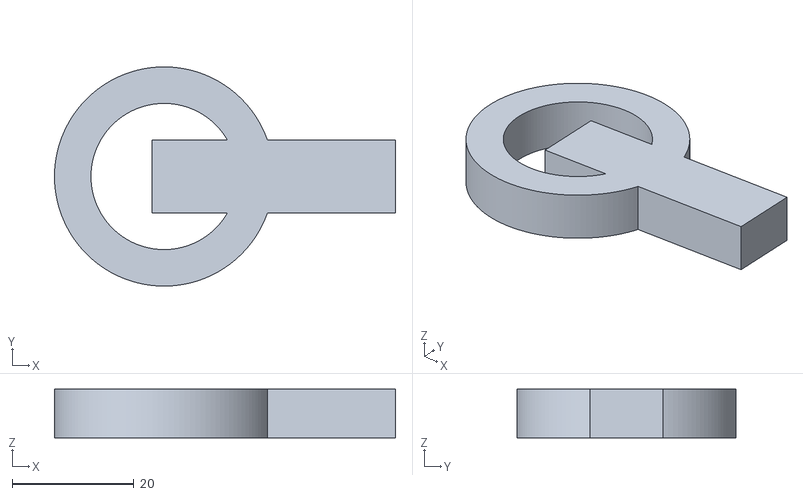
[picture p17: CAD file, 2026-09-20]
outputs/cad/stl/cable_guide.stl
56.0 x 36.0 x 8.00

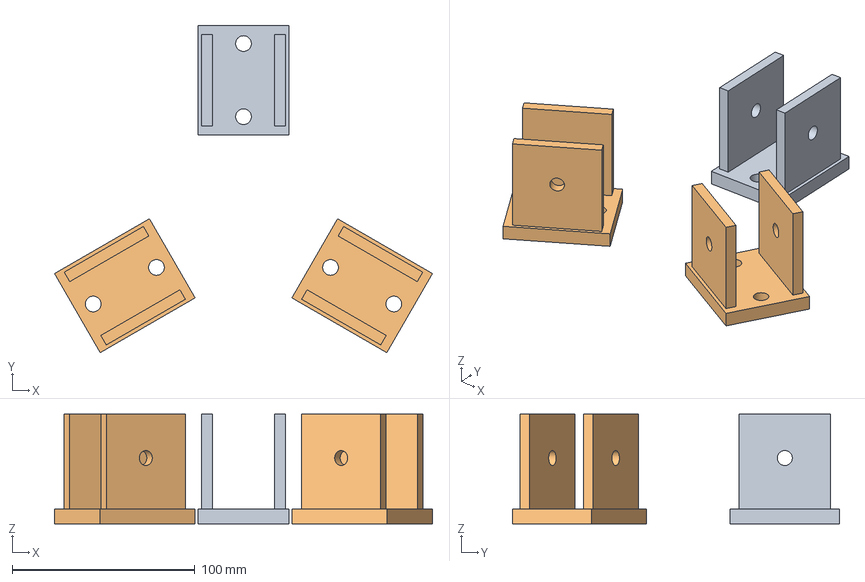
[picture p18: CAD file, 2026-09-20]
outputs/manual_3rps_rev_m1_fusion_native/groups/lower_joints.step
206.9 x 179.2 x 60.0 mm
A1_LOWER_ONE_PIECE_CLEVIS_A6061
A2_LOWER_ONE_PIECE_CLEVIS_A6061
A3_LOWER_ONE_PIECE_CLEVIS_A6061

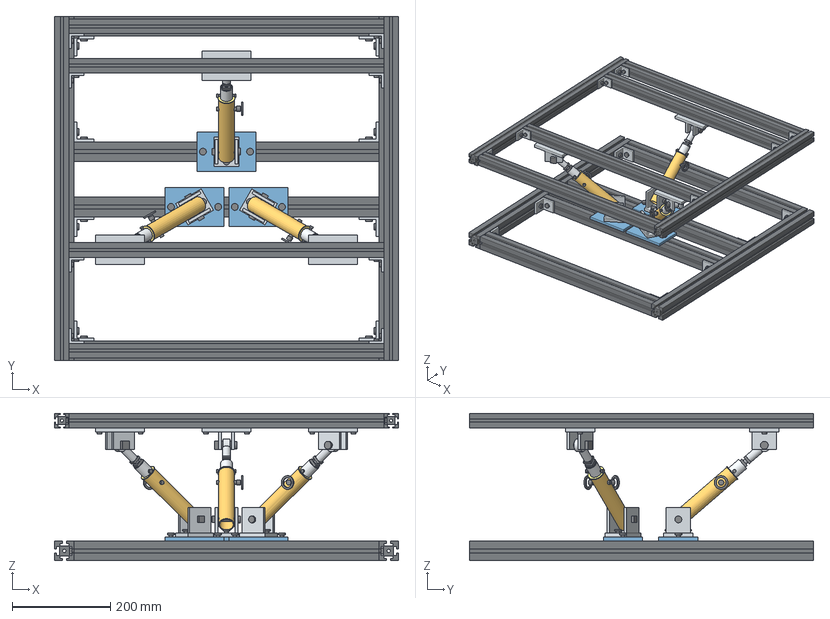
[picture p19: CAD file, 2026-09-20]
outputs/manual_3rps_rev_m1_fusion_native/Manual_3RPS_RevM1_NEUTRAL.step
700.0 x 700.0 x 300.0 mm
LOWER_SIDE_L_DNF4040_700
LOWER_SIDE_R_DNF4040_700
LOWER_CROSS_FRONT_DNF4040_620
LOWER_CROSS_A1_DNF4040_620
LOWER_CROSS_A23_DNF4040_620
LOWER_CROSS_REAR_DNF4040_620
BRACKET4035_1_L
BRACKET4035_1_R
BRACKET4035_2_L
BRACKET4035_2_R
BRACKET4035_3_L
BRACKET4035_3_R
BRACKET4035_4_L
BRACKET4035_4_R
A1_LOWER_ADAPTER_A6061_120x80x8
A2_LOWER_ADAPTER_A6061_120x80x8
A3_LOWER_ADAPTER_A6061_120x80x8
A1_LOWER_ONE_PIECE_CLEVIS_A6061
A2_LOWER_ONE_PIECE_CLEVIS_A6061
A3_LOWER_ONE_PIECE_CLEVIS_A6061
A1_OUTER_TUBE_OD32x2_L160_REAM28H7
A1_INNER_TUBE_OD25x2_L150_6POS
A1_IGUS_JFM_2528_21
A1_POM_LOWER_GUIDE_RING
A1_A6061_M10_THREADED_PLUG
A1_M10x1p5_FINE_STUD_L53
A2_OUTER_TUBE_OD32x2_L160_REAM28H7
A2_INNER_TUBE_OD25x2_L150_6POS
A2_IGUS_JFM_2528_21
A2_POM_LOWER_GUIDE_RING
A2_A6061_M10_THREADED_PLUG
A2_M10x1p5_FINE_STUD_L53
A3_OUTER_TUBE_OD32x2_L160_REAM28H7
A3_INNER_TUBE_OD25x2_L150_6POS
A3_IGUS_JFM_2528_21
A3_POM_LOWER_GUIDE_RING
A3_A6061_M10_THREADED_PLUG
A3_M10x1p5_FINE_STUD_L53
UPPER_SIDE_L_DNF3030_700
UPPER_SIDE_R_DNF3030_700
UPPER_CROSS_FRONT_DNF3030_640
UPPER_CROSS_A1_DNF3030_640
UPPER_CROSS_A23_DNF3030_640
UPPER_CROSS_REAR_DNF3030_640
DCB3025_1_L
DCB3025_1_R
DCB3025_2_L
DCB3025_2_R
DCB3025_3_L
DCB3025_3_R
DCB3025_4_L
DCB3025_4_R
A1_UPPER_ONE_PIECE_CLEVIS_A6061
A1_THK_PHS10_RH
A2_UPPER_ONE_PIECE_CLEVIS_A6061
A2_THK_PHS10_RH
A3_UPPER_ONE_PIECE_CLEVIS_A6061
A3_THK_PHS10_RH
BRACKET4035_1_L_BOLT_X
BRACKET4035_1_L_BOLT_Y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

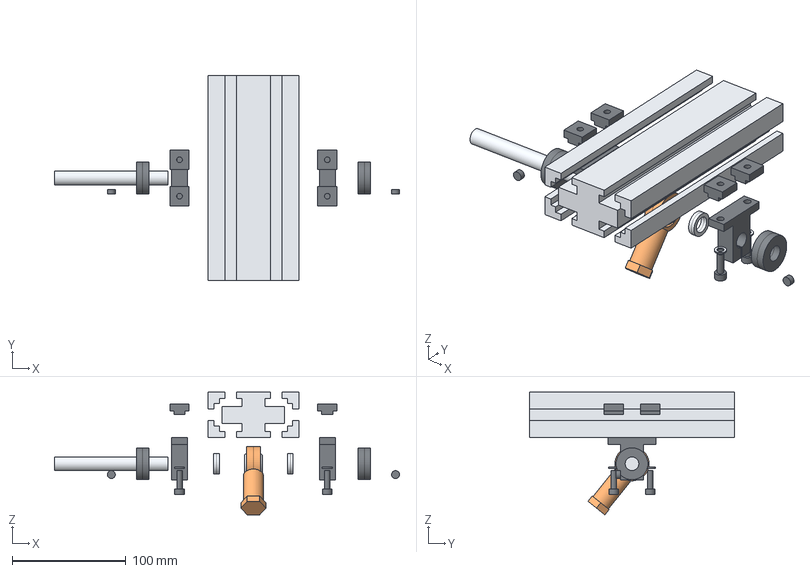
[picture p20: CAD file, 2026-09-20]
outputs/manual_m2r2f2_one_axis/step/A1_UPPER_EXPLODED_REVIEW.step
303.5 x 180.0 x 108.0 mm
UPPER_HFS8_4080
PHS12L_HOLDER
PHS12L_INNER_RING
U1_SHAT12_L
U1_L_M5X16_1
U1_L_W5_1
U1_L_HNTT8_5_1
U1_L_M5X16_2
U1_L_W5_2
U1_L_HNTT8_5_2
U1_SHAT_CLAMP_HEAD_L
U1_SHIM_STACK_L
U1_MCL12F_L
U1_SHAT12_R
U1_R_M5X16_1
U1_R_W5_1
U1_R_HNTT8_5_1
U1_R_M5X16_2
U1_R_W5_2
U1_R_HNTT8_5_2
U1_SHAT_CLAMP_HEAD_R
U1_SHIM_STACK_R
U1_MCL12F_R
U1_SHAFT12X100

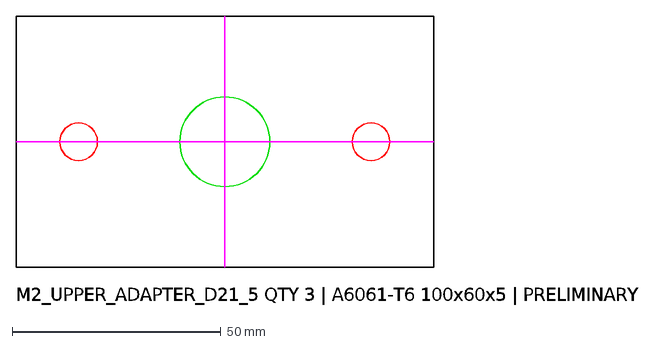
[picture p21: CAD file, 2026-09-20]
outputs/manual_turnbuckle_rev_m2/fabrication/M2_UPPER_ADAPTER_D21_5.dxf
M2_UPPER_ADAPTER_D21_5 QTY 3 | A6061-T6 100x60x5 | PRELIMINARY

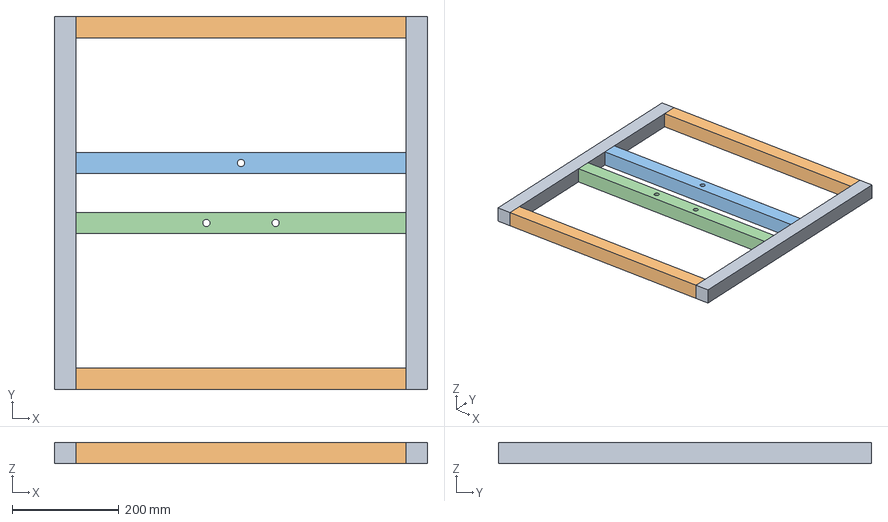
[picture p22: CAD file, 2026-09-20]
outputs/manual_turnbuckle_rev_m2/groups/lower_frame.step
700.0 x 700.0 x 40.0 mm

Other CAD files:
outputs/manual_m2r2f2_one_axis/step/A1_UPPER_ASSEMBLED_REVIEW.step
outputs/manual_turnbuckle_rev_m2/step/Manual_3RPS_RevM2_P3_RM3.step
outputs/manual_turnbuckle_rev_m2r1/export_diagnostics/check_0.step
outputs/manual_turnbuckle_rev_m2r1/step/M2R1_PM3_RM3_REVIEW.step
fabrication/profile_radial_revE_release_candidate_2026-09-04/C01_A1_LMB_RADIAL_ADAPTER.dxf
fabrication/profile_radial_revE_release_candidate_2026-09-04/C02_A2_LMB_RADIAL_ADAPTER.dxf
fabrication/profile_radial_revE_release_candidate_2026-09-04/C03_A3_LMB_RADIAL_ADAPTER.dxf
fabrication/profile_radial_revE_release_candidate_2026-09-04/C04_LOWER_STOP_CATCH_FRONT.dxf
fabrication/profile_radial_revE_release_candidate_2026-09-04/C05_LOWER_STOP_CATCH_REAR.dxf
fabrication/profile_radial_revE_release_candidate_2026-09-04/C06_UPPER_STOP_ANCHOR_FRONT.dxf
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

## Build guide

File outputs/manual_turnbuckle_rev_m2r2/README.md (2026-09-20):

# M2R2 — 기성 연결부 조립 CAD

**프로파일은 절단 주문, 접합부는 기성품 볼트 조립** 조건으로 바꾼 검토본이다. 기존 맞춤 평판과 Ø12/20 부시를 제거했다. 제작 승인 도면은 아니다.

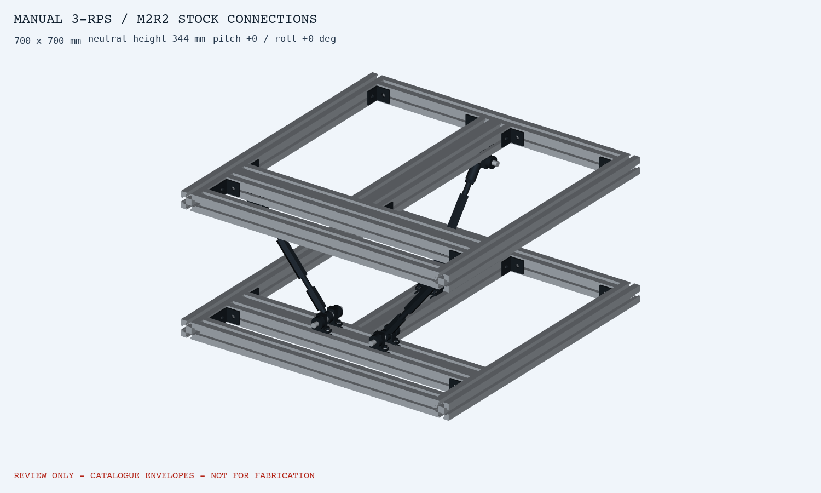
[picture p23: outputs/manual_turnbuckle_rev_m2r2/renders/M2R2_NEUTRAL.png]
전체 조립


## 변경점

- 턴버클3개 유지, 앞1/뒤2 직교 배치. 상하 프레임을 4040/4080 같은 계열로 통일.
- 관절: 슬롯에 직접 장착하는 SHAT12 두 개 + Ø12 축 + 기성 심 와셔 + 축 칼라.
- 맞춤 가공 부품 0종으로 계획. 정밀축도 카탈로그 길이 지정품이며 별도 끝단 가공 없음.
- 검토 크기700×700×344 mm. 기존보다44 mm 높고, 실제 카트 치수는 반영 전.

## 파일

- [전체 조립 STEP](step/M2R2_NEUTRAL_REVIEW.step)
- [기울어진 자세 STEP](step/M2R2_P3_R3_REVIEW.step)
- [링크 1개 STEP](step/M2R2_SINGLE_LINK_REVIEW.step)
- [부품 후보·절단 길이·조립 순서·근거](../../design_basis/manual_revm2r2_stock_connections_2026-09-05.md)
- [검사 결과 JSON](M2R2_AUDIT.json)

## 검증 결과

|항목|결과|
|---|---|
|모델 구성|156개 구성요소 / 전체 STEP246 솔리드|
|외형 간섭|대표9자세, 모델링한 서로 다른 구성요소 사이 간섭0건(교차부피0.01 mm³ 기준)|
|기구학|±3° 영역169자세, R 구속 rank3 / 링크 잠금 포함 rank6|
|필요 핀 간 길이|260.561~297.349 mm|
|검토 길이 범위|260~300 mm, 최소 내부 나사물림19.326 mm|
|종속 중심 이동|최대 X0.685 / Y0.274 mm, yaw=0 중립 근방 분기|
|STEP 재수입|3개 모두 형상 유효, 최대 부피차0.000014 mm³ 미만|

카탈로그 장착 치수 기반으로 만든 외형 CAD다. 프로파일 내부 단면과 브래킷 형상은 단순화했으며 브래킷 볼트, 지지대 클램프 나사, 칼라 체결나사는 생략했다. 따라서 위 결과는 전체 실물 조립의 모든 간섭·강도·공차 검증 완료를 뜻하지 않는다. 실제 제조사 CAD 기반 최종 검사는 남아 있다.

## 주문 전 남은 항목

1. STB 압축 사용과 지지대/칼라의 정격·체결 조건, 국내 공급/납기.
2. PHS12L 좌나사 및 아이/축/심의 실제 치수와 유격, M5 볼트 물림.
3. 독립 기계 스톱, 하부 고정 및 실제 카트의 위치결정·기계식 래치.

20 kg은 총 지지질량 예비 기준이며 실제 프레임·카트·적재물 합산 전이다. 이 문서는 상부 프레임과 링크 접합부의 무가공 조립안을 완성한 것으로, 전체 장치 구매 릴리스는 아니다.

## 재생성

Python3.12, CadQuery2.8, VTK9.6.2. 프로젝트 루트와 해당 라이브러리 폴더를 PYTHONPATH에 두고 `scripts/build_manual_turnbuckle_rev_m2r2.py` 실행. 이전 M2/M2R1의 형상 유틸리티와 M2 계산 모듈을 함께 사용한다.

이번 Windows 환경의 OneDrive `vendor/python` 접근 오류 때문에 별도 사용자 캐시 `C:/Users/Kangmin/.cache/leveling-cad-runtime`에 실행 의존성을 설치했다. CAD 실행은 결과 파일과 검사 완료 메시지를 기록한 뒤 종료코드1을 반환했다(최소 CadQuery import만 해도 재현). 이 런타임 종료 문제는 해결되지 않았으며 테스트 프로세스 전체가 정상 종료했다고 주장하지 않는다. JSON 결과, 각 STEP 재수입 결과, ZIP 무결성 검사는 구분해서 기록했다.

구매 발주, 공급사 문의 발송, 가공도·DXF, 실물 시험은 실행하지 않았다.

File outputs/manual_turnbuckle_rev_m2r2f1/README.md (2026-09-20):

# M2R2F1 — 체결 검토 수정본

프로파일 접합부의 제조사 도면을 대조하고 볼트·T너트·공구 접근을 추가 검토했다. **검토용 CAD이며 하중 지지능력/실물 체결 강도 승인본은 아니다.** M2R2의 가정 형상과 절단표를 아래 내용으로 대체한다.

- 일반 장착 볼트는 **M8×15 48개 / M5×16 24개**, 모두 일반 육각렌치 머리로 통일했다. 동봉 전용 M4와 턴버클 M12 나사는 별도 유지한다.
- M5 와셔는 **DIN433 5.3×9×1** 24개로 변경했다. T너트는 HNTT8-8 / HNTT8-5.
- 실제 브래킷40×40×30, 두께6 mm를 반영했다. 기존35 mm 가정으로 놓친 간섭을 해결하기 위해 뒤 가로재를20 mm 이동했다.
- **4080 앞 세로재 두 개의 절단 길이는450 mm**다. 기존470 mm로 주문하지 않는다. 외곽700×700×344 mm 유지.
- M5 체결 시 **지지대 동봉 M4 클램프 나사를 잠시 제거한 뒤 재조립**한다. 설치 상태 그대로는 렌치 경로가 막힌다.

## 파일

- [상세 체결 검증·볼트 목록·조립 순서](../../design_basis/manual_m2r2f1_fastening_2026-09-05.md)
- [중립 조립 STEP](step/M2R2F1_NEUTRAL_REVIEW.step)
- [기울기 STEP](step/M2R2F1_P3_R3_REVIEW.step)
- [링크 한 개 STEP](step/M2R2F1_SINGLE_LINK_REVIEW.step)
- [형상·공구 경로 검사](M2R2F1_AUDIT.json) / [체결 단면 수치](FASTENING_STACK_AUDIT.json)

## 검증 결과

264개 구성요소 / 전체354솔리드. 대표9자세 부품 교차 없음. 대표3자세에서 각84개 직선 렌치 삽입 경로를 검사했으며, 위 조립 순서 적용 후 방해 없음. 설치 상태의 M4 방해12건/자세는 JSON에 별도로 보존했다. STEP3개 재수입 유효, 최대 부피차0.000004 mm³ 미만. 169자세 길이261.379~296.532 mm, 최소 내부 나사물림19.734 mm.

M5/M8 장착 볼트 모두 슬롯 돌출9 mm, 공칭 나사 겹침6.5 mm, 바닥 여유3.5 mm. 지지대 받침은 슬롯 양쪽 각2 mm로 좁으며, 접촉압·국부 휨·미끄럼·체결 토크는 별도 확인이 필요하다. 나사 끝 불완전부를 제외한 유효 물림까지 보증한 값이 아니다.

CAD 단면의 일부 테이퍼·필릿, 칼라 전용 나사와 렌치 손잡이의 회전 범위는 생략했다. 제조사 대응 계열의 슬롯/너트 조합을 사용하며 실제 공차·하중 정격을 추정으로 확정하지 않았다. 기존 STB 압축 정격·기계 스톱·카트 연결부 미완료 상태 유지.

## 재생성

CadQuery2.8 / VTK9.6.2 환경에서 `scripts/build_manual_turnbuckle_rev_m2r2f1.py`; 단면 검사 `calculations/manual_m2r2f1_fastening.py`; 패키지 검사 `scripts/package_manual_turnbuckle_rev_m2r2f1.py`.

이번 환경에서는 CAD 결과 기록 후 프로세스 종료코드1 문제가 기존처럼 재현되었다. CAD 내부 검사 결과와 별개이며, 이 실행 자체가 정상 종료했다고 주장하지 않는다. 표준 Python의 체결 단면 계산과 작성 산출물 무결성 검사는 정상 종료했다.

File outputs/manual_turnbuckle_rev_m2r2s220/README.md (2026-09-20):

# Manual 3-RPS M2R2-S220

승인된 개념을 장바구니 미스미 대체품으로 치환한 Phase 2 CAD 검토본이다. 하부 관절을 기존 4080 슬롯 안쪽으로 옮겨 700×700×299.2 mm 중립 형상을 만들었다. 사용자 가공은 없고 프로파일 길이 지정만 필요하다. 현행 사용범위는 상부 패널 없이 알루미늄 프로파일을 노출하고 카트와 적재물을 올리지 않는 자중 전용 감독하 시연이다.

## 검증 결과

- ±3° 169자세: 링크 265.42~293.31 mm, 구속 랭크 3/잠금 랭크 6
- 대표 9자세: 예상 밖 부품 교차 0, 형상 오류 0
- 중립·±3° 복합자세 공구축: 예상 밖 방해 0
- STEP 3개 재읽기: 유효 형상 및 부피 일치
- A2 하부 SHAT12를 180° 돌려 인접 A3와의 M4 공구축 충돌을 제거함

## 파일

- `step/M2R2S220_NEUTRAL.step`: 중립 전체 조립체
- `step/M2R2S220_P3_R3.step`: pitch +3°, roll +3°
- `step/M2R2S220_SINGLE_LINK.step`: 한 축 상세
- `renders/`: 중립, 복합자세, 노출 링크, 한 축 이미지
- `M2R2S220_AUDIT.json`: 자세·간섭·공구·STEP 검증
- `FASTENING_STACK_AUDIT.json`: M5/M8 체결 깊이 검토
- `BOM.csv`: 주문 목록과 미결 품목
- `ASSEMBLY.md`: 위치와 조립 순서

IKO PHS12L은 공식 카탈로그의 보수 허용 편각8°가 계산 요구1.95°를 만족한다. 사용자 결정으로 독립 과조절 스토퍼, 전용 받침, 전용 시험대 고정품과 카트 래치는 현행 구매에서 제외한다. 이는 기계식 스토퍼나 하중 안전성이 검증됐다는 뜻이 아니다. 남은 구매 전 항목은 활성 20행 재검산과 최종 견적이다. 따라서 `PURCHASE_RELEASE=FALSE_PENDING_FINAL_QUOTE`, `FABRICATION_RELEASE=FALSE`다.

구매 전 점검: `../../verification/m2r2s220_no_cart_pre_purchase_audit_2026-09-07.md`

`PRELIMINARY PoC DESIGN — NOT APPROVED FOR FABRICATION — REQUIRES MECHANICAL ENGINEERING REVIEW`

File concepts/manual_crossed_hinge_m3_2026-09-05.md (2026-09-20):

# 최소 수동 수평조절 M3 — 직교 경첩 2축
> ARCHIVED_COMPARISON: 같은 날짜 후속 사용자 결정으로 Rev M2를 재활성화했다. 이 문서는 현재 제작/구매 방향이 아니다.
2026-09-05 | PRELIMINARY PoC DESIGN | NOT APPROVED FOR FABRICATION
REQUIRES MECHANICAL ENGINEERING REVIEW

## 결론
현재 목적에 대한 우선 검토안은 하부 받침 / 중간 틸트 프레임 / 상부 받침의 3단 구조다.
하부-중간은 Y방향 경첩축으로 pitch를 조절하고, 중간-상부는 X방향 경첩축으로 roll을 조절한다.
각 축의 반대편에 조절나사 한 개와 금속 접촉패드를 둔다. 나사 높이를 맞추고 잠금너트를 체결한다.
단순 볼트 끝을 판에 직접 비비지 않도록 회전 패드가 있는 조절나사를 후보로 둔다.
상판/중간판은 가공량과 질량에 따라 판재 또는 볼트조립 프레임으로 정한다. 세 장의 두꺼운 금속판으로 바로 확정하지 않는다.

## 비교 — 점수는 만들지 않고 작업 차이를 비교
| 안 | 장점 | 추가 수고/결함 | 판정 |
|---|---|---|---|
| 받침판+교환 심 | 움직이는 부품 최소 | 매번 들어서 심 교환, 2축 반복조절 번거로움; 포획/횡구속 필요 | 고정 자세 1회 시연만 필요하면 더 단순한 차선 |
| 나사 3개로 떠받친 상판 | 보기에는 단순 | 별도 X/Y/yaw 구속과 들림 방지 필요; 그냥 올려놓는 구성 불가 | 현재 선택 안 함 |
| 기존 턴버클 M2 | 기존 계산/모델 존재 | 세 링크 조절, 좌나사/부시/맞춤판 조달 | 보관 |
| 중앙 구면피벗+나사 2개 | 두 손잡이로 조절 | yaw 구속 추가 필요, 편심/들림 검토 | 현재 선택 안 함 |
| 직교 경첩+나사 2개 M3 | 축별 조절, 경첩이 상하 구조 연결 | 경첩 유격/정렬/정격, 3단 적층, 종속 중심 이동 | 우선 개념 |

전세계에서 부품 수가 절대 최소라는 의미가 아니다. 수동 반복 시연과 기계적 횡구속을 동시에 남기는 범위에서의 단순안이다.

## 조립 토폴로지
상부 하중 받침 + 필요한 카트 기계식 리시버
↕ 중간 프레임의 X축 경첩 1세트 + roll 조절나사 1개
중간 프레임
↕ 하부 프레임의 Y축 경첩 1세트 + pitch 조절나사 1개
볼트로 시험대에 고정하는 하부 장착부

경첩 1세트는 정렬된 금속 경첩 2개 또는 정격 확인된 연속 경첩 1개 후보다.
두 경첩의 회전축은 반드시 공선이어야 한다. 느슨한 가구용 경첩을 무조건 대입하지 않는다.
조절나사의 지지 너트/블록을 확실히 포획하고 풀림방지한다. 프로파일 T너트 단독을 긴 나사의 지지 베어링처럼 쓰지 않는다.
경첩축 높이에 스페이서를 두어 중립에서 상하 프레임을 평행하게 한다. 축 반대쪽이 중립보다 위/아래로 움직일 수 있는 간격을 확보해야 ±3°가 가능하다.
평평한 판을 경첩으로 바로 겹쳐 붙이는 구성은 음의 각도에서 닿을 수 있어 채택하지 않는다.
독립 기계식 상/하 각도 스톱과 풀리지 않는 포획 구조를 각 단계에 둔다. 스톱 위치 후보는 ±3.5°이며 허용차/접촉강도 검증 전이다.
나사 잠금너트는 나사 회전만 잠근다. 상판 들림 잠금으로 계산하지 않는다.
각 단계 반대편에는 조절 중 해제 가능한 금속 포획 클램프를 별도로 두어, 조절 완료 후 나사 접촉을 유지하고 들림을 제한한다. 경첩만으로 자유 가장자리 들림이 막힌다고 가정하지 않는다.
클램프는 기울어진 상태에서 걸림 없이 체결될 형식과 여유를 확인해야 하며, 현재 상세품 미선정이다.

## 자유도와 좌표
X: 길이, Y: 폭, Z: 위. pitch θ: 하부 Y축, roll φ: 중간 프레임 X축.
강체 이상모델 R=Ry(θ)Rx(φ). 독립 yaw 관절 없음. 이 순서의 ZYX Euler yaw는 0이나 가공 유격에 의한 흔들림은 별도 검사한다.
a: 하부 Y축 위 기준점, b: 중립 상태 상부 X축 위 기준점, p0: 중립 상판 기준점.
p=a+Ry(θ)[(b-a)+Rx(φ)(p0-b)].
중심 XYZ가 고정되는 구조가 아니다. 공통 Z 상승은 없지만 기울임에 의한 종속 Z 변화는 있다.
예시 a=(-125,0,0), b=(0,-125,40), p0=(0,0,80) mm, θ/φ=-3~3°를 0.5° 간격으로 169점 계산했다.
중립 대비 최대 |ΔX|=4.698 mm, |ΔY|=2.265 mm, |ΔZ|=13.239 mm.
이는 예시 기구의 산술 결과이며 치수 확정/실제 간섭검증이 아니다. 기존 요구의 절대 횡이동 금지 조건을 만족한다고 주장하지 않는다.

## 조절 범위 산술
경첩축에서 나사 중심선까지 수평 레버암 d, 하부 프레임 기준으로 수직인 나사를 가정:
h-h0=d tan(α), α=atan((h-h0)/d).
패드는 기울기를 수용하고 접촉점 미끄럼을 허용해야 한다. 나사축이 판과 함께 기울어지는 다른 배치에는 식을 그대로 쓰지 않는다.
| d mm | 중립 대비 나사 이동 mm | 총 이동 mm |
|---:|---:|---:|
| 200 | ±10.48 | 20.96 |
| 250 | ±13.10 | 26.20 |
| 300 | ±15.72 | 31.44 |
M12×1.75는 조절감 예시이며 확정 규격이 아니다. d=250 mm에서 중립 근처 1회전 약 0.401°, 1/4회전 약 0.100°.
나사 길이는 위 이동 외에 물림 길이, 잠금너트, 접촉패드, 스페이서가 필요하므로 아직 정하지 않는다.

## 하중 스크린과 미검증 범위
g=9.80665 m/s². 시험하중 10 kg는 기존 목표를 유지한다.
소형 시연 이동부 5 kg를 임시로 더한 총 15 kg와, 카트 10 kg까지 임시 포함한 총 25 kg를 각각 비교한다.
실제 프레임/카트/상판 질량은 측정해야 하며 25 kg는 상한 보증이 아니다.
예비 정적 안전율 SF=2: 부품 비교용 여유이며 인증/최종 설계 기준이 아니다.
W=mg; 총 25 kg에서 W=245.17 N, 2W=490.33 N.
한 단계 이상모델: 힌지-나사 거리 d=250 mm, 중력 작용선 거리 u=50/125/200 mm(중앙 및 ±75 mm 편심).
수직 지지력 Fv=Wu/d, 힌지 합성 수직반력 Hv=W-Fv.
접촉면 법선 반력을 보수적으로 Fv/cos(3°)로 비교하면 최대 196.40 N, SF 적용 392.80 N.
경첩 간격 s, 횡방향 CG편심 e일 때 경첩 두 개의 수직반력 근사는 H1,H2=Hv/2 ± We/s.
따라서 각 경첩에 합성반력의 절반만 적용하면 안 된다. e=±75 mm, s=250 mm, u=200 mm에서는 한쪽에 인장반력이 생길 수 있다.
상부 단계를 지지하는 하부 단계는 상부+중간 질량 모두 포함하고, 실제 기울어진 중력선과 CG 높이로 다시 풀어야 한다.
현재 계산은 나사/힌지 정격 선정 완료가 아니다. 브래킷 굽힘, 볼트 인장/전단, 나사 좌굴/물림, 판 처짐, 용접 없는 너트 포획, 클램프/스톱 강도는 미검증.
접촉 법선의 횡분력은 나사/경첩에 전달되므로 로드 단순 축력만으로 선정하지 않는다.
총 25 kg, 편심 75 mm 예시 하부 정적 모멘트는 각 축 18.39 N·m, SF 적용 36.77 N·m. 실제 모멘트는 CG 높이와 종속 변위까지 포함한다.
하부 지지면/고정볼트 자료가 없으므로 최소 장착면 크기와 전도저항을 확정하지 않는다. 시험대 고정 조건을 우선한다.

## 기능별 재료 후보 — 주문 BOM 아님
- 하부/중간/상부 구조재 3세트: 규격 프로파일 또는 판재. 정확 절단 수량 미정.
- 직교 회전축 2세트: 정격 확인된 금속 경첩, 스페이서 및 체결품.
- 손조절 나사+회전 접촉패드 2세트, 잠금너트 2개, 포획형 지지너트/블록 2개, 접촉판 2개.
- 각도 양방향 스톱 2축분, 포획 클램프 각 축 1세트 이상: 형식/개수 미정.
- 하부 시험대 고정 브래킷 및 체결품.
- 카트 리시버는 실측 이후 위치결정 블록/교체형 브래킷/기계식 래치 2개 이상/이탈방지 포함. 카트 몸체는 만들지 않는다.
- 수평 측정은 보유/대여 수평계를 먼저 사용. 구매 필요 여부 별도.
정확 SKU, 재료 등급, 두께, 홀 위치, 가격, 납기, 비용 인정은 미확정이다.

## 가장 짧은 검증 순서
1. 축소 성과와 예정 재료 목록의 비용분류를 담당자에게 확인할 짧은 설명 준비.
2. 카트 통합 필수 여부에 따라 외형을 정하고, 보유/구매 가능한 경첩·나사패드의 도면과 정격 확인.
3. 개념 승인 후 한 축으로 무부하 조절/잠금/스톱 기능부터 확인한 뒤 2축 결합.
4. 하부 고정, 상부 무부하, 클램프 해제 후 조절; 나사 잠금과 클램프 체결 후 하중 추가.
5. 수평계로 전후 값 기록. 10 kg에서 두 축 ±0.5° 이내 10초 유지 목표, 균열/풀림/들림/처짐 확인.
6. 0/±3° 조합 9자세 무부하 범위검사와 중앙/편심 하중 유지 확인. 허용 편심은 실물 강도검토 뒤 지정.
끼임 부위와 임시 받침 사용 위치를 표시한다. 사람 탑승, 이동 중 조정, 고속 보정은 범위 밖이다.
디지털 산술만 수행했으며 B-rep 간섭, 시제품 조립, 하중시험은 수행하지 않았다.

## 부품 원리 확인 출처
2026-09-05 열람. 제품 범주의 존재와 주의사항 확인용이며 구매 추천이나 국내 재고 근거가 아니다.
- KIPP 회전 접촉패드: https://www.kippusa.com/en-us/products/METRIC/Leveling-feet/Leveling-feet-machine-feet/Swivel-thrust-pads/p/agid.1210
- norelem 프로파일 경첩: https://www.norelemusa.com/en-us/hinges-for-aluminum-profiles
  소개 페이지 일부 경첩의 200 N 안내는 비구속 참고값이다. 본 구조에 충분하다고 판단하지 않았다.
- norelem 잠금 경첩 안내: https://www.norelemusa.com/us/en/Products/Product-overview/Systems-and-components-for-machine-and-plant-construction/27000-Clevis-joints-Rod-ends-Ball-joints-Axial-j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
  공개 하중값에 안전율이 포함되지 않는다는 주의가 있어 일반 경첩과 잠금 마찰을 무검증 확정하지 않는다.

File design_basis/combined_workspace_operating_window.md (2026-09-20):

# Combined Workspace Operating Window

Status: Phase 1 preliminary parameter screen. Not approved for fabrication.

## Purpose And Coordinate System

This screen selects a geometry candidate that can perform the user-confirmed full operating grid before detailed CAD:

- Material payload: 10 kg user-confirmed PoC basis. The workspace result is geometric; it does not increase any load claim.
- Vertical lift: 0, 50, 75, and 100 mm from the selected disconnected/collapsed pose.
- Pitch and roll: every nine combination of `-3, 0, +3 deg`.
- Coordinate origin: lower-platform center; `+X` is the 900 mm length direction, `+Y` the 800 mm width direction, and `+Z` vertical. Pitch is about `+Y`; roll is about `+X`.

For upper joint `u_i`, lower joint `b_i`, and platform height `z`, the calculation is:

```text
Li = || Ry(pitch) Rx(roll) ui + [0, 0, z] - bi ||
```

The preliminary actuator operating keep-out is `15 mm` from each catalogue end: `334 to 508 mm` for the 319 to 523 mm candidate actuator. This is a planning reserve for catalogue-end uncertainty, position-feedback/deceleration allowance, and assembly tolerance. It is neither the final mechanical-stop location nor an approval of the catalogue dimensions.

## Comparison Result

| Candidate | Collapsed device height | Guide outer / inner | Worst actuator soft reserve | Minimum guide overlap | Result |
|---|---:|---:|---:|---:|---|
| WS-01-H0 existing comparison | 250 mm | 190 / 200 mm | about 2.54 mm | 83 mm | Geometrically passes, but too tight for CAD baseline |
| WS-01-H20 recommended | 270 mm | 195 / 220 mm | about 11.13 mm | 88 mm | Recommended for pre-CAD parameter review |

The selected `270 mm` value stays inside the user-confirmed 250 to 300 mm disconnected-height envelope and is mechanically simpler than consuming the actuator retraction margin. The guide length change is needed because raising the collapsed pose without changing the guide would reduce the 100 mm-lift overlap below the existing 80 mm requirement.

## Recommended Candidate: WS-01-H20

| Parameter | Preliminary candidate | Reason |
|---|---:|---|
| Disconnected/collapsed device height | 270 mm | Retains practical lower-end reserve while staying in the approved envelope |
| Platform-joint height increase from older 250 mm layout | 20 mm | Raises the limiting retracted actuator length |
| Required lift from this new collapsed pose | 100 mm | Full user target remains checked |
| Outer keyed guide length | 195 mm | Restores overlap margin without a large package change |
| Inner keyed guide length | 220 mm | Keeps an 88 mm minimum overlap in the full grid |
| Actuator soft operating window | 334 to 508 mm | 15 mm candidate keep-out from 319/523 mm catalogue endpoints |
| Worst retraction-side soft reserve | about 11.13 mm | Occurs at 0 mm lift and a combined +/-3 degree corner |
| Worst extension-side soft reserve | about 73.80 mm | Occurs near 100 mm lift; not the limiting condition |
| Minimum guide-overlap reserve | 8 mm above the 80 mm rule | Occurs at 100 mm lift |

The guide calculations use overlap only. They do not establish guide side-load capacity, friction, wear-pad life, tube buckling, or stop impact capacity.

## Stop And Limit Requirements Carried Into CAD

1. The lower and upper lift hard stops must be separate physical parts. They cannot be the actuator's internal limit or an electrical switch.
2. Electrical upper/lower limit switches must open before the corresponding mechanical stop contact and must not be used as normal positioning feedback alone.
3. CAD must check every permitted pitch/roll and lift-stop contact permutation so that no actuator reaches the actual manufacturer end condition. The 15 mm soft window is a control target, not a claimed hard-stop clearance.
4. The current placeholder guide model puts generic stop blocks inside the guide assembly. It must be replaced by external shoulders/collars or equivalent geometry that cannot obstruct the sliding inner tube.
5. The YAW-A pitch/roll stops are four separate adjustable contacts at +/-7 degrees per yoke axis, as defined in `design_basis/yaw_a_gimbal_kinematic_definition.md`.

## Open Evidence Before Concept Approval

- Confirm the purchased actuator's actual pin-to-pin end dimensions, internal limit behavior, backlash, and deceleration/overshoot.
- Perform the yoke clearance/backlash gauge and the HRT8E 14 degree bracket gauge.
- Establish the lift-stop contact surfaces, their impact/load capacity, and their relationship to actuator endpoints in CAD.
- Recalculate moving/fixed mass split and actuator force after the 270 mm geometry is represented in CAD.

```text
WS-01-H20 SELECTED AS PRE-CAD PARAMETER CANDIDATE
NOT A FABRICATION GEOMETRY OR CONCEPT APPROVAL
```

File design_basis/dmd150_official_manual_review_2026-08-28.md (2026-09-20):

# DMD-150 Official Manual Review

Date: 2026-08-28

Status: **CONTROL INTERFACE CONFIRMED; ACTUATOR CURRENT AND REGENERATION PROTECTION REMAIN OPEN**

## Source Files

- `references/vendor_downloads/DMD-150_users_manual.pdf`: official Motorbank six-page user manual downloaded from the manufacturer's technical-data page.
- `references/vendor_downloads/arduino_ms-001_dmd-150_example.zip`: official Arduino example downloaded from the manufacturer's technical-data page.

## Confirmed Electrical Ratings

| Item | Official value | Design interpretation |
|---|---:|---|
| Supply range | DC 6.5 to 41 V | Compatible with the selected 12 V bus |
| Continuous current without added cooling | 12 A | Use as the default thermal limit until enclosure testing |
| Continuous current with simple cooling | 15 A | Requires demonstrated airflow and temperature margin |
| Output power at 12 V | 180 W | The distributor's generic 360 W label applies at 24 V, not 12 V |
| Logic high | 2.0 to 5.5 V | Mega2560 5 V logic is compatible |
| Logic low | 0 to 0.8 V | Use a common logic ground and defined startup states |
| PWM range | 0.1 to 100% | Ramp duty rather than making abrupt large changes |
| 5 V auxiliary output | 500 mA | Do not use it as the main Mega/BNO055 supply; retain E005 |
| Driver size | 55 x 55 x 35 mm | Use for enclosure layout |

The 110 A figure in the manual is an instantaneous MOSFET peak rating. It is not an allowable branch current or a basis for breaker, conductor or PSU sizing.

## Confirmed Control Truth Table

| IN1 | IN2 | PWM | Motor state |
|---:|---:|---:|---|
| 0 | 0 | 0 or 1 | Brake |
| 1 | 1 | 0 or 1 | Floating/coast |
| 1 | 0 | 1 or PWM | Forward / forward speed control |
| 0 | 1 | 1 or PWM | Reverse / reverse speed control |

The official Arduino example uses separate `IN1`, `IN2` and `PWM` outputs. Its `brake()` function drives both direction inputs low and PWM to zero; `floating()` drives both direction inputs high and PWM to zero. Mega2560 pins may be reassigned, but this logic must be preserved.

For a full-duty direction reversal, the manual calls for approximately 0.1 s of braking before applying the opposite direction. The control software shall also ramp PWM and prevent direct forward-to-reverse commutation.

## Regeneration And Protection Finding

The manual warns that motor inertia or lowering motion can return energy to the DC bus. A switch-mode power supply may respond by entering overvoltage protection. The manufacturer recommends a bidirectional TVS at the motor output and gives `1.5KE24CA` as an example, while also emphasizing controlled stopping and avoiding abrupt PWM changes.

This creates a real procurement gap:

1. identify a NAVIMRO-orderable bidirectional TVS or manufacturer-approved equivalent;
2. verify its stand-off, clamp voltage and pulse-energy rating against measured actuator regeneration;
3. define terminal placement and lead length in the wiring drawing;
4. confirm that the selected SMPS remains stable during loaded lowering and braking.

Do not treat the example TVS part number, or multiple TVSs in parallel, as an automatically validated final design. Pulse-current sharing and absorbed energy require a bench check.

## Remaining Release Gates

The driver interface itself is no longer an unknown. The remaining driver-system gates are:

- delivered actuator rated, starting and stall current;
- permitted one-, two- and three-axis concurrency;
- loaded-lowering regenerative voltage and energy;
- enclosure airflow and DMD-150 case temperature;
- final Mega2560 pin allocation, startup pull states and point-to-point wiring;
- single-axis current-limited commissioning before all three channels are enabled.

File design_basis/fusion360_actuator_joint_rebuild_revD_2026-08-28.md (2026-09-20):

# Fusion 360 actuator joint rebuild Rev D - 2026-08-28

## Decision

Keep the approved three-actuator radial mechanism, but replace the invalid Rev C U/H compound with one spherical rod end at each actuator end. The active joint is NAVIMRO `K02020097 / JMC JFT-8R`, quantity six. The DIHOOL U and H bracket rows remain in the BOM at quantity zero as audit history.

This is a preliminary stationary-PoC digital mock-up and is not approved for fabrication. The A2 actuator is still a conservative envelope because its exact delivered end interfaces and matching STEP have not been received.

## How one actuator is assembled

1. Bolt the lower `NVR-P04` spreader to the 640 mm lower actuator crossmember with two underside M8 screw/washer/T-nut sets.
2. Cut two `NVR-P16` lugs from 50x6 SS400 flat bar. Drill each Ø8.2 hole 15 mm from the free end.
3. Align both lugs around a 20 mm internal gap with an Ø8 jig pin, then weld them to the underside of P04. The pin, not the plate edge, controls coaxiality.
4. Fully engage the JFT-8R M8 female thread on the confirmed A2 end adapter and lock it with a jam nut. Do not use a long exposed threaded standoff.
5. Put one fitted spacer on each side of the 12 mm rod-end ball. Insert the M8 shoulder/part-thread pivot through lug, spacer, rod end, spacer and opposite lug, then positively retain it.
6. Repeat the same construction on the upper `NVR-P03` spreader. P03 bolts under the upper 660 mm member and its P16 lugs point downward.
7. Repeat the cassette at the other two 120-degree locations. The complete model contains six rod ends, twelve P16 lugs and six pivot stacks.

## Active dimensions

| Item | Rev D value |
|---|---:|
| Lower joint radius | 195 mm |
| Upper joint radius | 400 mm |
| Lower pin Z | -10 mm |
| Upper pin offset below platform datum | -38 mm |
| Yoke internal gap | 20 mm |
| P16 lug | 50x6x27 mm, Ø8.2 |
| Pivot | nominal M8, 36 mm modeled stack |
| Lower actuator crossmember | 640 mm |
| Upper end/crossmember | 660 mm |
| Disconnected collapsed module height | 300 mm |

## Verification

- Full lift sweep: 0 to 100 mm in 5 mm increments.
- Pitch and roll sweep: -3, 0 and +3 degrees at every lift point.
- Pin-centre length range: 269.040 to 394.209 mm inside the provisional 265 to 415 mm window.
- Worst joint-axis deviation: 9.852 degrees; required with one-degree margin: 10.852 degrees, below the JFT-8R catalog value of 13 degrees.
- Preliminary maximum actuator axial force: 876.4 N with project load factor.
- M8 pin double shear: 8.72 MPa; local pin bending screen: 87.17 MPa.
- 6 mm lug bearing: 18.26 MPa; lug root bending screen: 57.06 MPa.
- JFT-8R catalog breaking-load margin against twice the screened axial load: 4.25.
- Direct CAD intersection checks: no actuator-envelope/frame collision in collapsed, neutral, raised, max-pitch, max-roll or combined max-pitch-roll poses; no pivot overlap with modeled rod-end/lug/spacer bores.

## New DHLA6000 A2 supplier-page evidence

The official DIHOOL `DHLA6000-A2 24V` page was reviewed on 2026-08-28 after the user supplied the link. It describes A2 as a flat-base-plate plus M8-threaded installation and states that the central aluminum-tube mounting head is removable and replaceable. This supports keeping an explicit, replaceable M8 adapter component between the actuator envelope and JFT-8R rather than merging the joint into the actuator body.

The same page identifies a 72 W DHLA6000 family, displays 2.25 A on the 24 V page, and lists optional Hall sensors, built-in limits, IP43 and a 10% duty cycle. It also advertises a `DHLA6000-A2.STEP` file, but the direct file request returned HTTP 403 during this review.

These facts do not close the Rev D release gate. The active NAVIMRO BOM row is `K92931811 / LA2000-125150`, previously treated as a DHLA2000 12 V item. The DHLA6000 page does not establish the delivered K92931811 model, M8 thread gender, engagement length, supplied plates/accessories, pin-centre range or electrical current. Rev D geometry therefore remains unchanged and `A2_M8_INTERFACE_PROVISIONAL` remains provisional. Switching the purchase to DHLA6000 would require a new envelope, mass, interference, driver, supply and budget check.

The user confirmed on 2026-08-28 that NAVIMRO supplies the selected item as DC 12 V, 2000 N, 150 mm stroke and 5 mm/s. These four procurement specifications are now fixed for Rev D and the 12 V bus is selected. This confirmation does not identify the A1/A2 installation subtype or close the M8-interface, pin-centre, Hall, wiring, current or matching-STEP gates.

The official `DHLA6000-A2 12V` and `DHLA6000-A2 24V` pages use the same A2 outline image, installation description, interactive-model filename and STEP filename. Their page-level current values differ as expected, 4.5 A at 12 V and 2.25 A at 24 V. This is strong evidence that the two voltage variants share the mechanical DHLA6000-A2 hardware, although the manufacturer does not explicitly state interchangeability. It still does not prove that the selected `LA2000-125150` shares DHLA6000 geometry. The selected 2000 N / 5 mm/s combination also differs from the DHLA6000 table, which pairs 2000 N with 15 mm/s, so cross-family geometry remains prohibited without the actual K92931811 drawing or STEP.

## Remaining release gates

- Have the quotation and nameplate repeat DC 12 V, 2000 N, 150 mm stroke and 5 mm/s, and identify the exact manufacturer subtype and A1/A2 installation variant.
- Confirm whether each delivered A2 end is male or female M8x1.25 and provide the exact engagement length.
- Confirm supplier pin-centre minimum/maximum length, stroke, Hall option, wiring, rated/starting/stall current and matching STEP.
- Measure one received JFT-8R before freezing spacer thickness and shoulder-bolt grip length.
- Freeze P03/P04/P16 welding dimensions only after a one-cassette jig trial confirms free articulation without binding.
- Keep CR-3001 keeper/rating, shaft-collar holding data and remaining yellow transfer holes on hold.

## Fusion inspection files

- `outputs/navimro_fusion360_revD/step/ACT1_complete_mounting_cassette_neutral_revD.step`
- `outputs/navimro_fusion360_revD/step/NAVIMRO_detailed_neutral_revD.step`
- `outputs/navimro_fusion360_revD/step/NAVIMRO_module_only_collapsed_revD.step`
- `outputs/navimro_fusion360_revD/renders/actuator_joint_closeup.png`

Use the actuator-1 cassette first. It intentionally omits unrelated frame parts so the two P16 lugs, spacers, M8 pin, JFT-8R, A2 envelope and both supporting profile members can be inspected as one assembly.

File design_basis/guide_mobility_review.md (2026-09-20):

# Central Guide Mobility Review

Status: Phase 0 mobility review. Preliminary only. Not approved for fabrication CAD.

## 1. Purpose

This file resolves the next engineering question after the feedback review:

Can the central guide constrain X, Y, and yaw while still allowing Z, pitch, and roll?

The answer is conditional:

- Yes, if the central guide is a vertical keyed/torsion-transmitting telescoping member with a real yaw-transmitting two-axis Cardan/gimbal at the upper platform center.
- No, if the inner guide tube is rigidly fixed to the upper platform without a two-axis angular joint.

## 2. Coordinate basis

- X: lateral direction in upper platform plane.
- Y: fore-aft direction in upper platform plane.
- Z: vertical lift direction.
- Pitch: rotation about platform Y axis.
- Roll: rotation about platform X axis.
- Yaw: rotation about vertical Z axis.

Permitted active platform DOF:

```text
Z translation
Pitch
Roll
```

Mechanically constrained DOF:

```text
X translation
Y translation
Yaw
```

## 3. Required central guide architecture

The central guide must be treated as the main non-actuator constraint path:

1. Lower guide housing
   - Fixed to lower interface.
   - Constrains inner guide X/Y translation.
   - Constrains inner guide yaw through square/keyed/splined anti-rotation geometry.
   - Allows inner guide Z translation.

2. Inner telescoping member
   - Slides vertically.
   - Transmits yaw torque between upper Cardan/yoke and lower keyed guide.
   - Does not intentionally tilt with the upper platform.

3. Upper yaw-transmitting Cardan/gimbal
   - Located at the intended platform rotation center.
   - Has two intersecting horizontal rotational axes.
   - Allows platform pitch and roll relative to the vertical inner guide.
   - Constrains relative yaw between platform and inner guide.
   - Must not be a simple loose spherical joint unless a separate yaw anti-rotation path is added.

4. Upper platform
   - Rotates about the Cardan center for pitch/roll.
   - Its center point remains on the guide Z axis.

## 4. Constraint count

The platform has 6 rigid-body DOF before constraints:

```text
tx, ty, tz, rx, ry, rz
```

With a yaw-transmitting two-axis Cardan and keyed telescoping guide, the central guide constrains:

```text
tx = 0
ty = 0
rz = 0
```

Constraint rank = 3, leaving:

```text
tz, rx, ry
```

This is the desired platform mobility.

If the keyed guide is rigidly attached to the upper platform without a Cardan/gimbal, it constrains:

```text
tx = 0
ty = 0
rx = 0
ry = 0
rz = 0
```

Constraint rank = 5, leaving only:

```text
tz
```

That rigid arrangement would bind and is not acceptable.

## 5. Actuator joint requirement

The three actuators should control length only. They should not be relied on to constrain yaw or absorb guide side-load.

Therefore each actuator end must provide enough angular accommodation:

- Lower actuator joint: spherical rod end, true two-axis clevis/gimbal, or equivalent misalignment joint.
- Upper actuator joint: spherical rod end, true two-axis clevis/gimbal, or equivalent misalignment joint mounted to the rotating platform.
- A single-axis clevis pin is not enough unless the entire actuator motion is proven to remain in the clevis plane.
- Firgelli's 8.2 mm clevis hole is a connection interface, not by itself a proof of multi-axis misalignment capacity.

## 6. Numerical screening result

The script `calculations/mobility_analysis.py` was added.

Current results:

| Check | +/-3 deg | +/-5 deg | +/-8 deg |
|---|---:|---:|---:|
| Cardan combined tilt | 4.24 deg | 7.07 deg | 11.30 deg |
| Cardan 8 deg design angle | Pass | Pass | Fail |
| Cardan 10 deg hard stop | Pass | Pass | Fail |
| Max lower actuator joint deviation | 10.94 deg | 13.85 deg | 18.36 deg |
| Max upper actuator joint deviation | 7.08 deg | 7.68 deg | 9.47 deg |
| Actuator length Jacobian rank | 3 | 3 | 3 |
| Max normalized Jacobian condition | 1.45 | 1.50 | 1.63 |

The current geometry is not near a length-control singularity in the checked range. The remaining risk is not the actuator length mapping; it is the physical joint and central guide implementation.

## 7. Guide overlap screen

The current telescoping guide overlap screen gives:

```text
minimum_overlap_mm = 83
required_minimum_overlap_mm = 80
```

This only barely passes the preliminary overlap screen at full lift. It is not enough for fabrication approval because:

- UHMW shim clearance is undefined.
- Side-load and moment capacity are not calculated.
- Stop geometry and assembly tolerance are not allocated.
- The overlap check does not prove smooth sliding under load.

## 8. Current CAD limitation

The current CAD is a visual/parametric placeholder:

- `keyed_guide_inner` stays vertical.
- `cardan_head` is displayed at the platform center.
- The Cardan is not yet a real articulated assembly.
- Actuator joints are drawn as simple spheres, which is a placeholder for angular freedom.

Do not treat the current CAD as proof that the physical mechanism will articulate without binding.

## 9. Required next design decisions

Before parameter approval or detailed CAD, define:

1. Lower actuator joint type.
2. Upper actuator joint type.
3. Central guide lower bearing/slide construction.
4. Central guide upper Cardan/gimbal construction.
5. Whether the Cardan transmits yaw or whether a separate yaw link is required.
6. Cardan axis intersection tolerance.
7. Cardan design angle and hard stop angle.
8. Actuator joint allowable misalignment angle.
9. Guide overlap and side-load capacity.
10. Assembly clearance and shim/preload plan.

## 10. Recommendation

Keep the three-actuator concept direction, but keep `P-GDE-001` as `critical_open`.

The next engineering task should be a small physical or CAD-free bench mock-up of the central guide and Cardan principle before fabrication CAD. A simple test rig can verify whether pitch/roll motion stays smooth while yaw and X/Y remain constrained.

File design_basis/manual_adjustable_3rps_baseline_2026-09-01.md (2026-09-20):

# 수동 조절식 3-RPS 활성 설계 기준

작성일: 2026-09-01  
상태: **ACTIVE CONCEPT - PRELIMINARY - NOT READY TO ORDER OR FABRICATE**

## 1. 결정

전동 액추에이터와 전자제어를 현재 PoC 범위에서 제거한다. 기존 Rev D의 120 deg 방사형 지지점, 상·하부 프로파일 프레임과 3-RPS 운동학은 재사용하고, 각 LM4075OE 자리를 수동 길이조절 지지대로 바꾼다.

선호 기구는 다음 순서로 검토한다.

1. 사다리꼴 나사 기반 수동 스크루 스트럿
2. 좌·우 나사 턴버클형 스트럿
3. 텔레스코픽 튜브 + 포지티브 잠금핀 + 미세조절 나사

단순 텔레스코픽 마찰 클램프, 가스스프링, 일반 전산볼트만 노출된 장주 구조는 활성 후보로 확정하지 않는다.

## 2. 유지하는 기하

| 파라미터 | 값 | 비고 |
|---|---:|---|
| 플랫폼 외곽 후보 | 700 x 700 mm | 기존 Rev D 유지 |
| 하부 프레임 | DNF4040 계열 | 재검증 후 재사용 후보 |
| 상부 프레임 | DNF3030 계열 | 재검증 후 재사용 후보 |
| 지지점 방위각 | 90/210/330 deg | 120 deg 방사형 |
| 지지 반경 | 250 mm | 상·하부 동일 기준 |
| 중립 핀 길이 | 230 mm | 계산 기준 |
| Z 조절 목표 | 0-50 mm | 수동 공통 조절 |
| pitch/roll | 각각 +/-3 deg | 수동 차등 조절 |

기존 이상모델에서 27개 조합의 핀 중심 길이는 212.137-297.864 mm다. 205-305 mm의 설계 포락체를 유지하면 양끝 계산 여유는 약 7.14 mm다. 이 여유는 실제 나사 끝단, 베어링, 잠금너트와 브래킷 적층 전의 값이므로 제작 여유로 확정하지 않는다.

## 3. 수동 스크루 스트럿 개념

각 축은 다음 기능 블록으로 구성한다.

```text
하부 R축 핀 브래킷
  -> 하부 엔드 어댑터
  -> 회전 방지 외부 튜브
  -> 사다리꼴 나사 + 너트
  -> 수동 핸들 또는 육각 공구 입력
  -> 독립 잼너트/잠금장치
  -> 상부 구면 로드엔드
```

최종 제품 선정 전의 요구 사양은 다음과 같다.

- 핀 중심 최소 길이: 205 mm 이하 목표
- 핀 중심 최대 길이: 305 mm 이상 목표
- 정상 사용 계산 범위: 212.137-297.864 mm
- 사용 조절량: 최소 86 mm, 설계 목표 100 mm
- 정적 유지: 빈 카트 10 kg + 적재 10 kg + 상부구조 자중을 유지
- 조절 후 별도 잠금: 필수
- 회전 입력: 탈착 핸들 또는 육각 공구 방식 우선
- 세 축 길이 확인: 1 mm 이하 판독 가능한 눈금 또는 별도 게이지 후보

## 4. 조절 방법

### 전체 높이

세 지지대를 같은 길이만큼 조절하면 상판 높이를 바꾼다. 한 번에 한 축씩 조절할 때 상판 자세가 임시로 변하므로, 무부하·저속·감독하에서 작은 증분으로 A1-A2-A3 순환 조절한다.

### Pitch와 roll

목표 자세의 세 핀 길이는 기존 역기구학 계산으로 정한다. 각 지지대를 해당 길이에 맞춘 뒤 잠금너트를 체결하고, 기계식 수평계 또는 디지털 각도계로 실제 상판 각도를 확인한다. IMU 폐루프는 사용하지 않는다.

### 고정 전시 모드

움직임이 전혀 필요하지 않은 전시에서는 세 지지대를 230 mm 중립 길이에 잠근다. 이 모드는 자동 또는 수동 수평조절 성능을 증명하지 않는다.

## 5. 구조 재사용과 재설계 구분

재사용 후보:

- 700 mm 외곽의 4040 하부·3030 상부 프로파일 배치
- 90/210/330 deg 지지점
- 상부 범용 프로파일 인터페이스
- 기존 대표 자세와 간섭검사 절차

반드시 재설계:

- LM4075OE 솔리드와 LMB-10 전용 하부 브래킷
- 수동 스트럿 몸체·나사·너트·회전방지 구조
- 핸들/공구 접근 공간
- 잼너트 또는 잠금핀 접근 공간
- 상·하부 엔드 어댑터와 조인트 적층
- 기존 전동 종단용 스토퍼 형상
- 수동 길이 눈금과 조립·조절 순서

## 6. 현재 미확정 항목

- 사다리꼴 나사 호칭, 리드와 효율
- 너트 재질과 백래시
- 외부/내부 튜브 규격과 회전방지 방식
- 핸들 토크와 공구 규격
- 하중 상태 조절 허용 여부
- 하부 R축·상부 S축의 정확한 구매품
- 좌굴 안전율과 나사산 최소 물림
- 부식·마감과 외관 커버
- NAVIMRO 또는 다른 국내 공급처의 정확 SKU

이 항목을 웹 도면과 계산으로 닫기 전에는 CAD 제작치수나 최종 BOM을 발행하지 않는다.

## 7. 다음 설계 순서

1. 수동 리드스크루·턴버클·텔레스코픽 후보를 국내 구매 가능품으로 조사한다.
2. 205-305 mm 핀 길이와 100 mm 조절 범위를 만족하는 토폴로지를 선정한다.
3. 나사축 좌굴, 조절 토크, 잠금과 조인트 하중을 계산한다.
4. Rev D Fusion 조립체를 복제해 `Manual 3RPS Rev M1`로 재구성한다.
5. 중립, Z+50, +/-3 deg pitch/roll, 복합 자세의 간섭과 공구 접근을 검사한다.
6. 수동안 전용 구조 BOM과 조립도만 새 주문 기준으로 발행한다.

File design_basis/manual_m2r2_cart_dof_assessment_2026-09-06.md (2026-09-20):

# 장바구니 부품 기준 M2R2 설계·자유도 검토

검토일: 2026-09-06  
상태: `PHASE 1 PRELIMINARY` / `PURCHASE_RELEASE=FALSE` / `FABRICATION_RELEASE=FALSE`

## 결론

장바구니의 `STB-M12 + BJ761-12011N + NTFL12-36 + IKO PHS12L + SHAT12 + SFU12-100 + SCSJ12-6` 조합으로 수동 수평조절 기구는 성립한다. 하부 R축 세 개가 X, Y, yaw를 구속하고, 턴버클 길이 세 개가 Z, roll, pitch를 독립적으로 결정한다. 고정 높이에서 pitch/roll 각각 ±3°인 625개 자세를 계산했을 때 자유도 구속 랭크와 길이 범위를 모두 만족했다.

다만 기존 M2R2F1 관절 위치는 턴버클 길이 여유가 최악 자세에서 1.38 mm뿐이다. 같은 부품과 같은 프로파일 절단 길이를 유지하고 **하부 관절만 기존 4080 슬롯 안쪽으로 이동한 M2R2-S220**을 다음 CAD 기준안으로 권장한다. 이 안은 계산상 전체 높이를 약 344 mm에서 299.2 mm로 낮추고, ±3° 최악 길이 여유를 5.42 mm로 늘린다.

## 권장 개념 좌표 M2R2-S220

좌표계는 X=장치 길이, Y=장치 폭, Z=위쪽이며 pitch는 Y축, roll은 X축 회전이다. 단위는 mm다.

|항목|A1 전방|A2 후방 좌측|A3 후방 우측|
|---|---:|---:|---:|
|하부 R 중심 `b_i`|`[0, 30, 63]`|`[-30, -180, 63]`|`[30, -180, 63]`|
|상부 로컬 S 중심 `p_i`|`[0, 250, 0]`|`[-250, -180, 0]`|`[250, -180, 0]`|
|하부 R축 `a_i`|X|Y|Y|
|중립 핀 중심거리|280.0|280.0|280.0|

- 중립 상부 핀 높이: 236.205 mm
- 예상 전체 상단 높이: 299.205 mm
- 후방 SHAT12 발 사이 공칭 간격: 18.0 mm
- 프로파일과 주문 수량 변경: 없음
- 사용자 가공: 없음. SHAT12 위치만 T슬롯에서 맞춘다.

상부점은 `q_i = Ry(pitch) Rx(roll) p_i + t`, 링크 길이는 `L_i = |q_i-b_i|`로 계산했다. 하부 R 구속은 `a_i·(q_i-b_i)=0`이며, 선택한 yaw=0 분기에서 기울기에 따라 작은 종속 X/Y 이동만 발생한다.

## 자유도 판정

|상태|구속 자코비안 랭크|남는 자유도|판정|
|---|---:|---|---|
|턴버클 길이 조절 가능|3|Z, roll, pitch|의도한 3자유도|
|세 턴버클 잠금|6|없음|정적 자세 고정|

중립 자세에서 하부 R 구속은 X, Y, yaw를 각각 독립적으로 제거한다. ±3° 전 영역에서도 수동 상태 랭크는 3, 잠금 상태 랭크는 6이었다. 무차원화한 잠금 자코비안의 최대 조건수는 5.38로 계산되어 조사 영역에서 사점이나 랭크 손실은 나타나지 않았다.

이 결과는 강체 관절 중심 모델의 순간 자유도 판정이다. 프로파일 휨, 축/아이 유격, 나사 백래시와 슬롯 미끄럼은 포함하지 않았다.

## 각도별 운동 범위

|pitch/roll 정사각 범위|최소 길이|최대 길이|최악 길이 여유|최대 턴버클 회전량|필요 PHS 편각|판정|
|---|---:|---:|---:|---:|---:|---|
|각각 ±3°|265.42 mm|293.31 mm|5.42 mm|4.17 회전|1.95°|통과|
|각각 ±5°|254.95 mm|301.54 mm|−5.05 mm|7.16 회전|3.34°|길이 실패|
|각각 ±8°|238.09 mm|313.02 mm|−21.91 mm|11.97 회전|5.54°|길이 실패|

따라서 현재 부품 조합의 설계 목표는 **pitch/roll 각각 ±3°**로 유지하는 것이 타당하다. ±5°와 ±8°는 기구학적 자유도 자체는 유지되지만 턴버클의 검토 길이 `260–300 mm`를 벗어난다.

±3° 전 영역에서 길이만 고려한 공통 Z 여유는 `−9.76~+9.89 mm`다. 이는 약 19.66 mm의 동시 높이변경 가능성을 뜻하지만, 이번 PoC의 독립 리프트 기능으로 승인한 값은 아니다. 실물 간섭, PHS 편각, 스톱과 하중을 포함한 검증 전에는 수평조절 전용으로 사용한다.

## 대표 조절량

STB-M12는 우·좌나사가 동시에 움직이므로 몸통 1회전에 핀 중심거리가 3.5 mm 변한다고 두었다. 양수는 신장, 음수는 수축이다.

|목표 자세|A1|A2|A3|
|---|---:|---:|---:|
|Pitch +3°, Roll 0°|0.00 회전|+2.29 회전|−2.34 회전|
|Pitch 0°, Roll +3°|+2.24 회전|−1.64 회전|−1.64 회전|
|Pitch +3°, Roll +3°|+2.23 회전|+0.84 회전|−4.17 회전|
|Pitch +3°, Roll −3°|−2.39 회전|+3.80 회전|−0.46 회전|

실제 조절은 상판을 별도 받침으로 지지한 무하중 상태에서 수행하고, 목표 자세 후 모든 공급 잠금너트와 외부 잠금너트를 체결한다. 눈금 표시는 ±3° 운전 범위에 두고 독립 기계식 과조절 스톱은 약 ±3.5° 후보로 다음 단계에서 형상 검토한다. 전기식 리미트와 기계식 스톱은 별개다.

## 하중 화면검토

10 kg 시연 적재물과 상부 프레임·접합부를 합쳐 총 지지질량을 임시로 20 kg으로 두었다. 실제 총질량은 계측해야 한다. 정적 수직하중만 분배한 결과는 다음과 같다.

|20 kg 하중 조건|최소 수직반력|최대 링크 축력 절대값|600 N 화면검토값 대비 비율|판정|
|---|---:|---:|---:|---|
|상판 중심|57.02 N|139.28 N|4.31|세 링크 압축|
|중심에서 100 mm 편심, 전 방향|11.52 N|216.76 N|2.77|세 링크 압축|
|중심에서 150 mm 편심, 전 방향|−11.22 N|255.50 N|2.35|일부 방향에서 한 링크 인장|

`600 N / 요구축력`은 부품 정격이 아니라 기존 개념의 화면검토 하중 대비 비율이다. STB-M12 압축 정격, SHAT12 클램프 유지력, T슬롯 미끄럼, 충격과 피로가 확인되지 않아 시스템 안전율은 아직 확정할 수 없다. 초기 시연은 적재물 중심 편심 100 mm 이내, 정지 상태, 하부 프레임 고정 조건으로 제한하는 편이 합리적이다.

## 장바구니 부품 반영

- `SCSJ12-6`: 기존 MCL-12-F보다 폭과 외경이 작아 공간 간섭은 악화시키지 않는다. 축방향 유지력은 실물 당김시험이 필요하다.
- `NTFL12-36`: 기존 M12×36 연결너트와 길이·나사 규격이 같아 관절 중심거리 식을 유지한다.
- `FWSSB-D9-V5.5-T1`: 내경만 0.2 mm 커지고 외경·두께가 같아 운동학 변화가 없다.
- `PCIMR/CIMR 12×18`: 공칭 적층 외형이 같아 운동학 변화가 없다. 납품품 폭을 재고 심 조합을 맞춘다.
- `IKO PHS12L`: 계산상 필요한 최대 편각은 1.95°다. IKO 카탈로그의 보어 12 mm PHS 허용 편각은 장착 형상에 따라 α1=8°, α2=13°이므로 보수적으로 8°를 적용해도 6.05° 여유가 있다. [IKO 공식 카탈로그](https://www.ikont.co.jp/global_data/download/pdf_catalog/cat5508.pdf)

## 남은 위험과 다음 CAD 검증 항목

1. M2R2-S220은 후방 SHAT12 발 사이 공칭 간격이 18 mm다. 주물 필릿, M5/M4 렌치 접근과 칼라 공구 회전공간을 3D로 다시 확인해야 한다.
2. 더 기울어진 링크 때문에 중심하중 최대 축력이 기존 좌표의 107.8 N에서 139.3 N으로 증가한다. 그래도 600 N 화면값 아래지만 NBK가 STB-M12에 하중 정격이나 압축 구조용 용도를 공개하지 않았으므로 공급사 확인 또는 1축 proof test가 필요하다. [NBK STB-M12 공식 페이지](https://www.nbk1560.com/en-US/products/machine_element/structurecomponents/STB/STB-M12/)
3. 독립 기계식 스톱 형상, 하부 시험대 고정, 실제 카트 위치결정·기계식 래치는 아직 확정되지 않았다.
4. 실제 카트 치수·질량·무게중심·체결홀은 제공되지 않았으며 이미지에서 추정하지 않았다.
5. 이 결과는 인증, 현장 안전 또는 사람 탑승 적합성을 뜻하지 않는다.

## 계산 산출물

- `calculations/manual_m2r2_cart_dof_simulation.py`: 현재 M2R2F1 자유도·길이·하중 계산
- `calculations/manual_m2r2_slot_layout_optimization.py`: 같은 장바구니 부품을 유지한 슬롯 위치 최적화
- `outputs/manual_m2r2_cart_dof_simulation/dof_simulation_results.json`: 현재 좌표 전체 격자 결과
- `outputs/manual_m2r2_cart_dof_simulation/slot_layout_optimization.json`: 권장 좌표와 ±3/5/8° 비교
- `outputs/manual_m2r2_cart_dof_simulation/recommended_standard_pose_adjustments.csv`: 권장안 대표 조절량
- `outputs/manual_m2r2_cart_dof_simulation/workspace_margin_and_joint_angle.png`: 현재 좌표의 ±3° 작업영역
- `outputs/manual_m2r2_cart_dof_simulation/slot_layout_optimization.png`: 슬롯 위치에 따른 높이·여유 비교
- `outputs/manual_m2r2_cart_dof_simulation/recommended_joint_centre_geometry.png`: 권장 관절 중심 개념도

PHASE 1 COMPLETE — WAITING FOR CONCEPT APPROVAL

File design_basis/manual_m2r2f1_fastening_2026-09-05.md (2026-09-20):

# M2R2F1 체결 검증과 볼트 통일

2026-09-05. 최신 실행본. **도면 기준 장착·나사 물림·공구 접근 검토 완료, 실물 체결 강도 검증은 미완료.** 기존 M2R2 CAD의 가정 오류를 수정했다.

## 확인 결과와 변경

|검토 항목|결과 / 반영|
|---|---|
|SHAT12 구멍과 슬롯|Ø5.5 구멍2개, 피치32를 같은 슬롯 방향으로 배치. M5 사용. 구멍 확대 불필요|
|두 지지대 간격|4080 슬롯 피치40, 지지대 축방향 폭14 → 안쪽26 mm 유지|
|지지대 받침|14 mm 폭이 10 mm 슬롯을 가로질러 양쪽2 mm씩 걸침. 직사각형 접촉 계산168 mm²/지지대. 설치 형상은 성립하지만 좁은 접촉면의 하중 정격을 입증한 것은 아님|
|슬롯 단면|이전 CAD 턱4 mm를 도면5.5 mm로 수정. 전체 깊이12.5 mm|
|T너트|이전 단순6 mm 블록을 HNTT8 전체높이9 mm, 돌출부3 mm로 수정. 나사 시작면은 프로파일 표면 아래2.5 mm|
|프레임 브래킷|이전35×35×4 외형은 잘못된 가정. 실제 HBLSSB8은 다리40, 폭30, 두께6, 구멍 위치30/20 mm|
|브래킷 간섭|뒤쪽 공간70 mm에 다리40 두 개가 들어가10 mm 겹침. 뒤 가로재를 Y−200→−180 mm 이동, 간격90 mm로 확보하여 여유10 mm|
|프로파일 절단 변경|앞 세로4080 길이470→450 mm 두 개. 나머지 길이 유지. 외곽700×700×344 mm 유지|
|M5 와셔|외경10은 발 끝까지 공칭 여유0. 외경9의 DIN433 M5(5.3×9×1)로 변경하여0.5 mm 확보|
|공구 접근|M4 클램프 머리가 M5 장착 볼트의 직선 렌치 경로를 가림. M4를 잠시 제거하고 M5 체결 후 M4 재조립하는 순서 필요|

## 통일한 체결품

|용도|정확 규격|조립 수량|육각렌치|구매 방식|
|---|---|---:|---|---|
|프로파일 프레임 브래킷 전부|M8×15 육각렌치볼트|48|6 mm|HBLSSB8-SET 24세트의 지정 동봉품 사용. 검정형 HCBMT8-15 표기를 공급사 확인|
|SHAT12의 상하 장착 전부|M5×16 일반 육각렌치볼트, 전나사|24|4 mm|표준 ISO4762/DIN912 계열, 특수 끝단·저두형 제외|
|지지대 볼트 와셔|DIN433 M5, 5.3×9×1 mm|24|—|표준 소형 평와셔|
|프레임 T너트|HNTT8-8|48|—|브래킷 세트 동봉, 별도 중복 구매하지 않음|
|지지대 T너트|HNTT8-5|24|—|선입형|
|예외: 지지대/칼라 내부|제조사 동봉 M4 등 원품|각 제품 동봉|일반적으로3 mm, 실제 동봉품 확인|나사 길이 임의 통일·교체 금지|

일반 장착 볼트는 두 종류다. 모든 볼트를 M8로 바꾸면 SHAT12 구멍 가공이 필요하고, 프레임을 M5로 바꾸면 제조사의 표준 체결 조합에서 벗어난다. 길이를 억지로 같게 맞추지 않고 두 용도에서 슬롯 안쪽 돌출 길이를9 mm로 맞췄다. M12 턴버클 나사·잠금너트는 조절 기구의 구성품으로 유지한다.

## 나사 물림 / 바닥 여유

지지대 M5: 볼트16−발두께6−와셔1=슬롯 안 돌출9 mm.

프레임 M8: 볼트15−브래킷6=슬롯 안 돌출9 mm. 동봉 조합에 추가 와셔를 임의로 넣지 않는다.

두 경우 모두 공칭 나사 겹침 = 9−(턱5.5−너트 돌출부3)=**6.5 mm**. 슬롯 바닥 여유 = 12.5−9=**3.5 mm**.

이는 나사 형상을 생략한 길이 계산이다. 볼트 끝 불완전 나사, 너트 입구 모따기 등을 제외한 유효 물림과 체결토크를 확정한 수치가 아니다. 임의 공차 민감도 계산에서도 간섭은 생기지 않았으나, 그 공차는 공급사 보증값이 아니다. 수치는 `FASTENING_STACK_AUDIT.json`에 남겼다.

## 반드시 따를 조립 순서

1. 선입 T너트를 프로파일 끝에서 넣고 프레임을 조립한다. 끝단 탭과 추가 구멍은 없다.
2. SHAT12의 동봉 M4 클램프 나사를 빼 둔다. 분실하지 않도록 지지대별로 묶는다.
3. 축을 두 지지대에 통과시켜 정렬하고, M5×16 + DIN433 와셔로 지지대를 슬롯에 체결한다. 여기까지는 M4 머리가 없는 상태로 렌치를 넣는다.
4. M4를 다시 넣어 축을 클램프하고 칼라를 장착한다. 모든 조립·재체결은 무부하/상부를 별도 받침으로 지지한 상태에서 한다.
5. 상부 지지대도 동일 순서로 조립한다. 상하에서 볼트·와셔 길이를 바꾸지 않는다.

지지대 고정 상태에서 M4를 제거하면 축 유지 상태가 달라진다. 하중이 실린 상태에서 이 순서로 풀거나 재체결하지 않는다. 칼라 전용 나사의 상세 공구 경로와 렌치 손잡이 전체 회전 범위는 이번 자동 검사의 범위 밖이다.

## 검사 범위

- 9자세의 서로 다른 모델 부품 교차 검사. 프레임 M8 볼트48개와 T너트48개, 지지대 M4 머리12개를 새로 포함했다.
- 중립과 ±3° 동시 기울기 두 자세, 총3자세에서 각84개 렌치 삽입 경로. M5/M8는 길이60 mm, M4는50 mm 직선 경로를 검사했다.
- 설치 상태의 M4 머리 간섭을 감추지 않고 `installed_clamp_obstructions`에 기록했다. 위 조립 단계에서 해당 M4를 제거하면 남는 간섭은 없다.
- STEP3개를 재수입하여 유효성과 부피를 재대조했다. 실제 숫자와 해시는 최신 출력 폴더 JSON이 기준이다.

단면의 테이퍼·필릿은 일부 단순화했다. HFS8과 HNTT8의 규격 호환성은 제조사 대응 계열로 확인했다. 공차, M5 체결 토크, 좁은 받침부의 국부 휨과 접촉압, 미끄럼 저항·반복하중은 형상 검사로 대체하지 않는다. 따라서 **상부 프레임에 장착할 수 있는 치수와 조립 순서는 확인했지만, 허용하중이나 최종 체결 강도를 승인한 것은 아니다.** 기존 STB 압축 정격·기계 스톱·실제 카트 인터페이스 미확정 상태도 유지한다.

## 제조사 근거와 확인한 도면

- [MISUMI 축 지지대 카탈로그](https://uk.misumi-ec.com/files/images/products/docs/shaftsupports.pdf), PDF7쪽 오른쪽: SHAT12 장착 피치32, 발두께6, 폭14, 축높이23, 체결구멍5.5, M4 클램프.
- [MISUMI HFS8-4080 단면](https://kr.misumi-ec.com/pdf/fa/2015/p2_0659.pdf), 왼쪽 HFS8 형상: 슬롯 폭10, 피치40, 턱5.5 및 내부7.
- [MISUMI 프레임 부품 카탈로그](https://it.misumi-ec.com/files/images/products/docs/framingsupport.pdf), PDF74쪽 HBLSSB8 / 82쪽 HNTT8: 브래킷 실제 치수와 지정 볼트, T너트 돌출형 단면.
- [Filtomatic DIN433 제조사 표](https://www.filtomatic.com/download/din-433/): M5 내경5.3, 외경9, 두께1.
- [NBK 육각렌치볼트 표준 치수](https://www.nbk1560.com/images/en-US/product/technical_data/rokkaku_bolt_NBK/rokkaku_bolt_NBK_1.pdf): 일반 볼트 머리와 렌치 치수. 특수 도그포인트 제품은 선정하지 않았다.

도면 PDF와 확인용 페이지 이미지는 `web_research/evidence/2026-09-05/m2r2_fasteners/`에 저장했다. 공급사 문의나 구매 발주는 하지 않았다.

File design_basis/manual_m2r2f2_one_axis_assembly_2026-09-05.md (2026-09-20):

# M2R2F2 한 축 상·하부 접합부 3D 조립 검토

2026-09-05. 사용자 요청에 따라 A1 한 축을 전체 장치에서 분리하고, 하부 R 관절과 상부 S 관절을 조립/분해 상태로 다시 모델링했다. 검토용이며 구매·제작 릴리스가 아니다.

## 먼저 정정할 점

모든 제품의 모든 치수를 확인한 상태는 아니다. 이번 검토에서 조립 성립에 직접 필요한 카탈로그 치수는 확인했다. 주물 필릿, 테이퍼, 나사산, 그리스 니플, 로드엔드 내부 부시, 칼라의 슬릿 같은 상세 형상은 일부 단순화 또는 생략했다. 실제 납품품 공차와 하중 정격은 실물/공급사 확인 대상이다.

## 한 축의 조립 구조

```text
하부 4080 프로파일
  └─ HNTT8-5 + DIN433 M5 와셔 + M5×16
      └─ SHAT12 두 개
          └─ Ø12×100 축
              └─ [5.9 심] - BJ761-12011N - [5.9 심], 총 0.2 유격
                  └─ DIN6334 M12×36 + STB-M12
                      └─ PHS12L
                          └─ [5.0 심] - PHS 내륜16 - [5.0 심]
                              └─ Ø12×100 축 + SHAT12 두 개
                                  └─ 상부 4080 프로파일
```

축 양 바깥에는 MCL-12-F 칼라가 지지대 외측면에 닿는다. 칼라는 축 이탈 억제용이고 지지대는 축을 클램프한다. 하부 회전은 BJ761 아이와 축 사이에서, 상부 기울기 보정은 PHS12L의 구면 내륜에서 발생한다.

## 확인한 핵심 치수

|부품|조립에 사용한 확인 치수|
|---|---|
|SHAT12|보어12, 축높이23, 발길이42, 축방향 폭14, 장착피치32, 구멍5.5, 발두께6, 클램프 M4|
|HFS8-4080|40×80, 슬롯폭10, 슬롯피치40, 상부 턱5.5, 슬롯 바닥 깊이12.5|
|HNTT8|17×17, 전체높이9, 돌출부3, M5/M8 규격|
|BJ761-12011N|보어12 +0.2/0, 폭14 0/−0.2, 외경25, 중심-끝50, M12×1.75, 나사부30|
|PHS12L|보어12 H7, 내륜폭16, 홀더폭12, 홀더외경30, 구면외경22.225, M12×1.75 좌나사|
|MCL-12-F|보어12 +0.050/+0.012, 외경28, 폭11 +0.076/−0.254, M4×12, 3 mm 렌치|
|STB-M12|M12×1.75, 최소 길이171, 양쪽 스터드 돌출24, 조인트너트 대변19|

## 적층 검토

두 SHAT12는 4080의 40 mm 피치 슬롯에 하나씩 놓인다. 각 지지대의 축방향 폭이14 mm이므로 안쪽 면 간격은 40−14=26 mm다.

- 하부: 5.9 + BJ761 폭14 + 5.9 =25.8 mm. 총0.2 mm, 좌우 공칭0.1 mm 유격을 남긴다.
- 상부: 5 + PHS 내륜폭16 + 5 =26 mm. 공칭 맞닿음이다. 실제 폭 공차를 측정한 후 기성 DIN988 심 조합만 바꾼다.
- 축:100 mm. 지지대 외측 간격54 mm, 칼라 두 개22 mm를 포함하면76 mm이므로 양끝에 공칭12 mm씩 남는다.
- 칼라: 보어가 축보다 +0.012~+0.050 mm 크며 M4×12 클램프 체결로 고정된다.

## 3D 검사 결과

|모델|구성요소|예상 밖 교차|형상 오류|
|---|---:|---:|---:|
|A1 전체 축|46|0|0|
|하부 조립|23|0|0|
|상부 조립|24|0|0|
|하부 분해|23|0|0|
|상부 분해|24|0|0|

STEP 5개를 다시 읽어 모든 솔리드 유효성을 확인했다. 최대 부피 차는 0.000001 mm³보다 작다. 접촉 거리 검사에서 하부 지지대-심 사이가 좌우0.1 mm다. 축은 공칭11.996 mm로 모델링하여 조임 전 SHAT12 보어와 반경방향0.002 mm 거리가 있으며, 슬릿 M4를 체결해 축을 잡는 구조다. 나머지 의도한 면 접촉은 수치오차 범위에서0 mm다.

## 모델에서 단순화하거나 아직 확인하지 않은 것

- SHAT12 주물 필릿·구배와 실제 클램프 슬릿 상세
- 프로파일 장착면 이외의 내부 공동 일부
- HNTT8 아래 테이퍼와 나사 입구 상세
- BJ761 아이-축부 연결 필릿과 실제 나사산
- PHS12L 그리스 니플, 구리 부시/소켓 내부 및 실제 나사산
- 전체 축 모델의 MCL-12-F 슬릿과 M4 체결나사 형상
- 실제 납품 폭에 따른 최종 DIN988 심 수량
- STB 압축 허용, SHAT 클램프 유지력, 프로파일 슬롯 턱의 국부 휨·미끄럼 정격

따라서 3D 모델은 **카탈로그 공칭 치수상 조립 방법과 공간 적합성**을 확인한 것이다. 실물 끼움, 체결토크, 허용하중을 확정한 결과는 아니다.

## 조립 순서

1. HNTT8-5 두 개씩을 각 슬롯에 넣는다.
2. SHAT12의 동봉 M4 클램프 나사를 잠시 제거한다.
3. M5×16 + DIN433 M5 와셔로 두 지지대를 느슨하게 장착한다.
4. 칼라-지지대-심-BJ761/PHS-심-지지대-칼라 순서로 Ø12 축을 통과시킨다.
5. 축으로 두 지지대 보어를 맞춘 뒤 M5를 체결한다.
6. SHAT12의 M4를 다시 조립하여 축을 클램프하고, 양쪽 MCL-12-F를 지지대 외측면에 붙여 체결한다.
7. 무부하/상판 별도 지지 상태에서 턴버클과 상하 관절을 연결한다.

## 근거 도면

- `web_research/evidence/2026-09-05/m2r2_fasteners/shaftsupports.pdf` PDF7쪽: SHAT12.
- `web_research/evidence/2026-09-05/m2r2_fasteners/profile4080.pdf`: HFS8-4080.
- `web_research/evidence/2026-09-05/m2r2_fasteners/framingsupport.pdf` PDF82쪽: HNTT8.
- `web_research/evidence/2026-09-02/manual_rev_m2/imao_bj761.pdf`: BJ761.
- `web_research/evidence/2026-09-05/m2r2_fasteners/thk_phs.pdf`: PHS12L.
- `web_research/evidence/2026-09-05/m2r2_fasteners/ruland_mcl12f.pdf`: MCL-12-F.
- `web_research/evidence/2026-09-02/manual_rev_m2/nbk_stb.pdf`: STB-M12.

검사 수치와 해시는 `outputs/manual_m2r2f2_one_axis/M2R2F2_ONE_AXIS_AUDIT.json`이 기준이다.

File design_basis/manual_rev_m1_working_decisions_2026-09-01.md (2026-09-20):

# Manual 3-RPS Rev M1 working decisions

Date: 2026-09-01
Status: design in progress; not released for purchase or fabrication

## Selected topology for detailed CAD

Each powered LM4075OE axis is replaced by one two-stage manual strut:

1. A 32 mm OD x 2 mm wall x 160 mm aluminium outer round tube.
2. A 25 mm OD x 2 mm wall x 150 mm aluminium inner round tube.
3. Six coarse positions at 15 mm pitch, retained by an 8 mm positive-lock pin.
4. A 0-15 mm M10 x 1.5 fine adjustment screw.
5. A THK PHS10 female rod end at the upper joint.
6. An M8 lower pivot in a bolted A6061 clevis.
7. An igus JFM-2528-21 flanged sleeve bearing at the upper end of the outer
   tube and a custom POM lower guide ring at the lower end of the inner tube.

The intended pin-centre adjustment is 205-295 mm. Coarse travel is 75 mm and
fine travel is 15 mm. The fine adjuster is disconnected from the upper pin,
turned, locked with jam nuts, and reconnected while the upper frame is
independently supported. Adjustment under payload is not allowed.

## Geometry retained from powered Rev D

- Lower frame: 700 x 700 mm, DNF4040 profile family.
- Upper frame: 700 x 700 mm, DNF3030 profile family.
- Support azimuths: 90, 210, and 330 degrees.
- Lower support radius: 75 mm.
- Upper support radius: 250 mm.
- Lower pin centre Z: 84 mm.
- Upper ring centre Z at collapsed neutral: 235 mm.
- Allowed motion: Z 0-50 mm, pitch/roll +/-3 degrees.
- Three local lower adapters: A6061-T6, 120 x 80 x 8 mm. There is no central
  hub plate.

The Rev D spatial constraint model, rather than the earlier equal-radius
screen, is the active kinematic datum for Rev M1. Its 27-pose grid requires
218.958-279.846 mm pin-centre length, leaving about 13.96 mm lower margin and
15.15 mm upper margin in the selected 205-295 mm manual range.

## Product-backed dimensions to verify before CAD release

- DNF4040 and DNF3030 section, slot, and centre-bore dimensions.
- 4035 and DCB3025 frame connector envelope and hole positions.
- THK PHS10: M10 x 1.5 female thread, 10 mm bore, 26 mm outer diameter,
  14 mm inner-ring width, 43 mm ring-centre-to-thread-end dimension, and
  8 degree minimum listed permissible tilt angle.
- IMAO BJ775-08040-SUS: 8 mm shank, 40 mm grip length, 9.4 mm ball diameter,
  8 mm end allowance, and 65 kN listed minimum double-shear force.
- igus JFM-2528-21: 25 mm nominal shaft, 28 mm housing bore, 35 mm flange
  diameter, 21.0 mm bearing length, and 1.5 mm flange thickness. The upper
  21.0 mm of the outer tube is finish-reamed to 28H7 after cutting.

## Active axial stack, local to each strut

- Lower pivot centre: `s = 0 mm`.
- Outer tube: `s = -16 to 144 mm`.
- Outer coarse-pin hole centre: `s = 115 mm`.
- Inner tube at coarse position 0: `s = 8 to 158 mm`.
- Inner-hole offsets from its lower end: 107, 92, 77, 62, 47, and 32 mm.
- At coarse position 75 mm, the remaining telescopic overlap is 61 mm.
- PHS10 thread end is 43 mm below its ring centre.
- The fine-adjuster free span is 4-19 mm for each coarse position, producing
  pin-centre lengths of 205-295 mm without relying on thread runout.

Tube mill tolerance is not assumed. Each supplied tube is measured before
machining; the bushing housing is finish-reamed and the POM guide ring is
finish-fitted to the measured bores and shafts.

The first Fusion interference run found and corrected three real layout
problems: the plug cross-bolt was moved below the M10 stud engagement, the
upper clevis gap was increased from 16 to 20 mm with two 3 mm side shims, and
the upper profile fasteners were moved outboard on a 100 mm base. These are
active design dimensions, not optional assembly adjustments.

The corrected Fusion run exposed a second issue: the M5 plug-retainer head and
nut touched the JFM flange. The retainer was therefore changed to M4 and placed
22.5 mm below the inner-tube end, leaving modelled clearance to both the JFM
flange and the end of the M10 stud.

## Release gates

- Complete detailed product-image evidence register.
- Generate a native Fusion 360 assembly with separately named components and
  all pins, bolts, nuts, spacers, tubes, clevises, and joint hardware.
- Pass assembly, interference, and section checks three times.
- Generate a flat BOM and repeat BOM-to-CAD checks three times.
- Repeat the complete audit once after any corrections.

`purchase_release=false`

`fabrication_release=false`

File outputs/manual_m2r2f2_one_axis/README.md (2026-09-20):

# M2R2F2 한 축 접합부 3D 검토

하부 R - 수동 STB-M12 - 상부 PHS12L로 이어지는 A1 한 축을 실제 배치에서 분리했다. 조립본3개, 분해본2개, STEP5개를 제공한다.

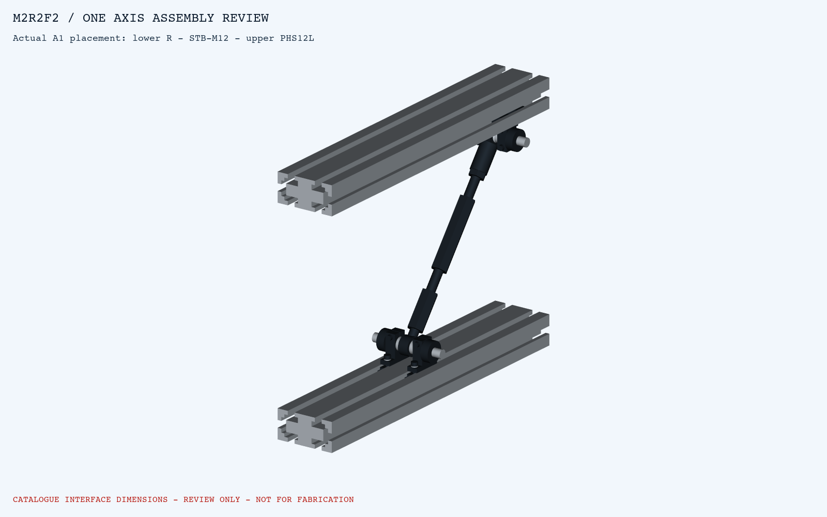
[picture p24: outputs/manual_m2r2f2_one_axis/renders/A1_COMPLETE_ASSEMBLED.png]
한 축 전체


## 바로 볼 파일

- [한 축 전체 STEP](step/A1_COMPLETE_ASSEMBLED_REVIEW.step)
- [하부 조립 STEP](step/A1_LOWER_ASSEMBLED_REVIEW.step) / [하부 분해 STEP](step/A1_LOWER_EXPLODED_REVIEW.step)
- [상부 조립 STEP](step/A1_UPPER_ASSEMBLED_REVIEW.step) / [상부 분해 STEP](step/A1_UPPER_EXPLODED_REVIEW.step)
- [확인 치수·조립 순서·미확정 항목](../../design_basis/manual_m2r2f2_one_axis_assembly_2026-09-05.md)
- [검사 JSON](M2R2F2_ONE_AXIS_AUDIT.json) / [구성요소 목록](COMPONENT_REGISTER.json)

## 하부와 상부

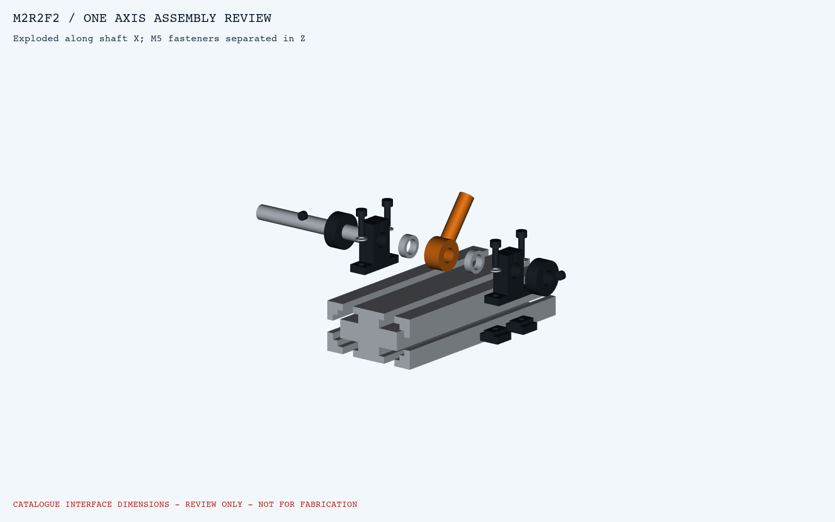
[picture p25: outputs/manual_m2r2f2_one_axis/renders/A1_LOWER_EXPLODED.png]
하부 분해


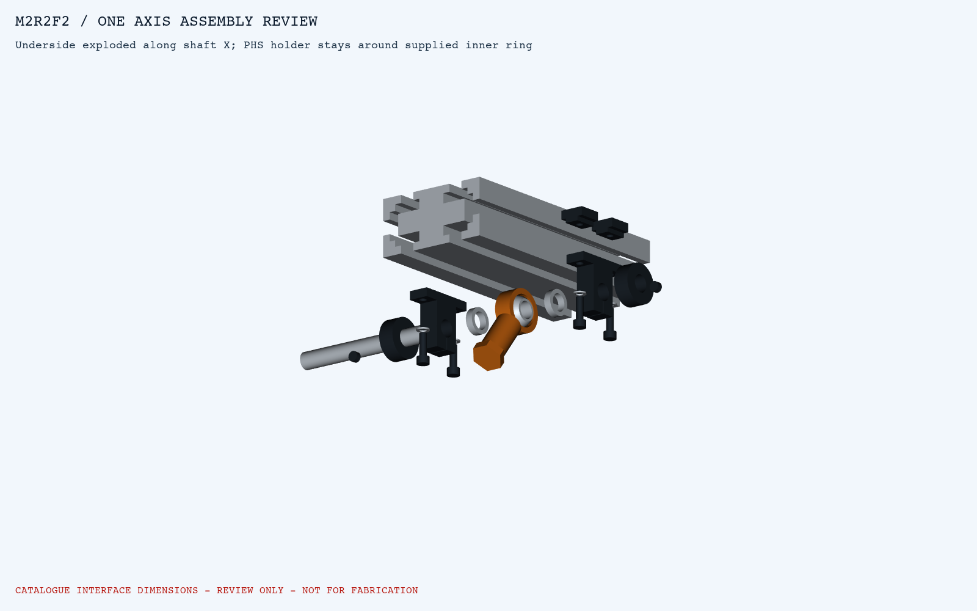
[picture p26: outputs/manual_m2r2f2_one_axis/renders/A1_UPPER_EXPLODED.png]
상부 분해


하부 적층은5.9+14+5.9 mm에 총0.2 mm 유격, 상부는5+16+5 mm다. 두 지지대 안쪽 간격26 mm, 축은 Ø12×100 mm다. 모델 축은11.996 mm로 두어 조임 전 보어 반경방향 거리가0.002 mm이며 SHAT12 슬릿 체결로 고정한다.

5개 모델의 예상 밖 교차0건/형상오류0건, STEP5개 재수입 통과. 주물 필릿·나사산·내부 부시·칼라 슬릿 등은 일부 생략했으므로 카탈로그 공칭 치수상 조립/공간 검토 결과다. 실물 끼움, 체결 강도와 허용하중 승인은 아니다.

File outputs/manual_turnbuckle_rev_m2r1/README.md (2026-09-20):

# Manual 3-RPS Rev M2R1 — CAD 검토 패키지
2026-09-05 | PRELIMINARY — NOT APPROVED FOR FABRICATION

## 먼저 열 파일
- `step/M2R1_NEUTRAL_REVIEW.step`: 색상과 부품 이름을 가진 전체 조립체. Fusion에서 업로드/열기 가능. F3D 원본은 생성하지 않았다.
- `step/M2R1_P3_R3_REVIEW.step`, `step/M2R1_PM3_RM3_REVIEW.step`: 복합 기울기 검토.
- `step/M2R1_UPPER_JOINT_REVIEW.step`: 한 축 상부 연결부.
- `step/M2R1_UPPER_JOINT_EXPLODED_REVIEW.step`: 상부 연결부 분해 표시. 분해 오프셋은 제작 치수가 아니다.
- `renders/NEUTRAL.png`, `renders/STRUCTURE_EXPOSED.png`, `renders/UPPER_JOINT_SECTION.png`, `renders/UPPER_JOINT_EXPLODED.png`.

## 이번 CAD에서 바뀐 것
기존 Rev M2는 보존했다. 수정본은 `cad/manual_turnbuckle_rev_m2r1.py`다.
- 실제 상부 포크의 큰 핀 구멍을 표현하고 독립 부시 6개를 넣었다.
- 구면 로드엔드 외륜 하우징과 상부 핀을 따르는 내륜을 분리했다.
- 내륜 양옆 지지용 스페이서 6개를 추가했다. 기존 BOM에 없던 항목이므로 견적/조립 목록에 반영해야 한다.
- 핀 머리·와셔·잠금너트와 평활 몸통 길이를 모델링했다. 기존 M12x65 표기를 임시 M12x80 검토안으로 변경했다.
- 기존 상하 프레임/지지점/링크 길이 계산은 유지하고 은색 프레임·검은 연결부·A1/A2/A3 라벨을 반영했다.
- 프로파일을 제조사 상세 단면으로 바꾸거나 생성형 이미지처럼 링크 위치를 바꾸지 않았다.

## 검증
수정본 112개 이름 있는 구성요소, 169개 솔리드. 9자세에서 모든 서로 다른 구성요소 쌍을 AABB로 추린 뒤 OpenCascade 교차체적으로 검사했다.
현재 기록은 `M2R1_CAD_AUDIT.json`을 따른다. 부품 간 판정 임계 교차체적은 0.01 mm³다.
복합 링크 내부의 중첩 나사 표현은 별도 부품 간 검사에 포함되지 않는다. 나사는 원통 외형으로 표현했고 실제 나선 공차를 검증하지 않았다.
중립 STEP를 재수입해 전체/개별 솔리드 유효성과 원본 부피 일치를 확인했다.
새 구면 형상의 초기 STEP 재수입 오류를 발견해 회전 단면으로 다시 작성한 후 9자세와 재수입을 다시 검사했다.
이 결과는 정격/내구/현장 안전/실제 공급품 조립성 검증이 아니다.

## 가정과 미확정 항목 — 발주 전 필수
- 포크 간격 22.4, 보어 20.1, 부시 OD19.98/ID12.1, 몸통 길이 11, 플랜지 OD26/두께1.5 mm는 공칭 조립 검토값이다. 실제 공급 보어/공차에 맞춰야 한다.
- 구면 내륜 OD24/폭16, 하우징 OD30/폭12/구면 시트OD24.2는 공급자 STEP가 없는 근사 외형이다. 구면 좌면/베어링 정격을 제작 지정한 것이 아니다.
- 내륜 스페이서 두께는 `(실제 포크 간격 - 실제 내륜 폭)/2`. 현재 3.2 mm는 중립 공칭값이다. 실제 편차는 측정 후 심/스페이서로 맞춰야 하며 고정 3.2 mm 6개를 바로 가공하면 안 된다.
- 임시 M12x80 핀의 평활 몸통 50 mm를 가정했다. 마지막 부시 끝 대비 평활부 여유는 0.6 mm에 불과하므로 공급 공차/와셔/목부분을 확인하기 전 확정품이 아니다. 하중 접촉부에 나사산이 걸리면 다시 선정한다.
- 재질 색은 구분용이며 부시 재질/윤활/압입/빠짐방지의 최종 선정은 아니다. 부시 플랜지는 외측에 있고 핀 머리·와셔·너트로 포획하는 개념이다.
- STB 압축 사용, 정확 LH 로드엔드/너트, 하부 핀 리테이너, 프레임 체결품 상세, 독립 기계 스톱, 실제 카트 리시버·하부 고정은 아직 열려 있다.
- 총 이동질량/CG 및 하중편심은 실측 후 확인한다. 수동 ±3°와 10 kg 시험하중이 목표이며 실물시험 미실시다.

## 부품 변경표 — 주문서 아님
| 기존 항목 | 수정본 |
|---|---|
| M07 부시 6개, 추상 표시 | 독립 플랜지 부시 6개, 공차/재질 미확정 |
| 내륜 양옆 부품 없음 | 스페이서 6개 추가, 실제 폭 측정 필요 |
| M08 M12x65 | M12x80/평활50 임시 검토, 정확 SKU 미확정 |
| 상부 로드엔드 한 덩어리 | 외륜/내륜 분리 표현; 실제 구매는 로드엔드 3개 |
| 청색 어댑터 표현 | 기본 금속 표면 + 축 식별 라벨 6개 |

구매/제작 승인은 false다. 제조용 DXF/공차도는 새로 발행하지 않았다.

## 재생성
Python 3.12, CadQuery 2.8, VTK 9.6 환경에서 프로젝트 루트를 PYTHONPATH에 포함하고 `scripts/build_manual_turnbuckle_rev_m2r1.py`를 실행한다.
이 프로젝트의 `vendor/python`에 의존성이 있다. `MPLCONFIGDIR`/`XDG_CACHE_HOME`은 프로젝트 내부 캐시 폴더로 지정한다.

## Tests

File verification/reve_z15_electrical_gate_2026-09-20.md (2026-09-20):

# Rev E Z+15 electrical gate — 2026-09-20

## Result

**HOLD — electrical architecture basis coherent; no ordering or motor-power release.**

| Checked item | Result | Reason |
|---|---|---|
| HMI-less operator path | PASS-BASIS | Laptop USB is the only start path; HMI/IF01 excluded from the new intent. |
| DMC bus separation | PASS-BASIS | Portenta J5 short daisy chain for DMC #1/#2/#3 only. |
| IMU bus separation | PASS-BASIS | Ethernet to isolated tGW-715i-T candidate, then separate Modbus RTU #11/#12. |
| Motor PSU sizing basis | PASS-BASIS | 3 × provisional 7.5 A × 1.25 = 28.125 A; select a 24 V 30 A class only after SKU gate. |
| DMC nominal current comparison | PASS-BASIS | 1.5 A loaded per axis is below stated 8 A continuous capacity; exact peak behaviour is not established. |
| DMC encoder / three-node RS-485 compatibility | REQUIRED / OPEN | Verify DMC 5 V encoder supply/output current, A/B logic/pull-up, 6 ppr count scaling, address 1/2/3 multidrop settings and reverse escape after an internal limit. |
| Independent motor power interruption | REQUIRED / OPEN | E-stop contactor/disconnect rating and selected SKU are not yet evidenced. |
| Regular HOME | PASS-RULE | Must not seek limits; requires saved state, Z=15 datum and no-move evidence. |
| Commissioning/recovery HOME | LIMITED | Block-supported and supervised only; cannot automatically enable LEVEL. |
| Z+15 synchronization | PASS-DOCUMENT | Physical Z=15~65 mm, command Z=0~50 mm, nominal range 221.281~289.523 mm and provisional 218~292 mm are synchronized. |

## Mandatory holds before any order or powered actuator test

1. `HOLD_ACTUATOR_SWITCH_POINTS`
2. `HOLD_ACTUATOR_PEAK_STALL_CURVE`
3. `HOLD_DMC_ENCODER_MULTIDROP_COMPATIBILITY`
4. `HOLD_DMC_STOP_BEHAVIOR`
5. `HOLD_SG01_QUOTE_CARD_STOCK`
6. `HOLD_SMPS_30A_SKU`
7. `HOLD_ESTOP_DC_INTERRUPTION_RATING`
8. `HOLD_BENCH_VERIFY`
9. `HOLD_PHYSICAL_CABLE_GUIDE_VERIFICATION`
10. `HOLD_NO_INDEPENDENT_MECHANICAL_STOPS`

The last hold is a project-rule conflict, so no electrical document may turn `PURCHASE_RELEASE`, `FABRICATION_RELEASE`, `CONTROL_POWER_TEST_RELEASE`, or `MOTOR_POWER_RELEASE` true.

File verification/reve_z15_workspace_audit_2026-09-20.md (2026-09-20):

# Rev E physical Z=15--65 mm workspace audit

## Result

`PASS-DIGITAL` — preliminary finite CAD/kinematics screen only. It does **not** grant fabrication or purchase release.

## Exact finite grid

| Dimension | Samples | Values |
|---|---:|---|
| Physical Z | 11 | 15, 20, …, 65 mm |
| Pitch | 13 | -3.0, -2.5, …, +3.0° |
| Roll | 13 | -3.0, -2.5, …, +3.0° |
| Pose samples | 1859 | 11 × 13 × 13 |
| Pin-length evaluations | 5577 | three axes per pose |

The retained `revd_data.pin_lengths` calculation returned a minimum of **221.281490 mm** at physical Z=15 mm, pitch=+3.0°, roll=+3.0°, axis 3; and a maximum of **289.522702 mm** at physical Z=65 mm, pitch=-3.0°, roll=-3.0°, axis 3. This is within the finite-screen bounds 221.0--290.0 mm.

## Rev E CAD collisions at physical Z=65 mm

`cad.profile_radial_reve_actual_vendor.collision_audit` was run for the required nine pitch/roll corner-and-centre combinations.

| Pitch (°) | Roll (°) | Result | Maximum unintended intersection (mm³) |
|---:|---:|---|---:|
| -3.0 | -3.0 | PASS | 0.000000 |
| -3.0 | +0.0 | PASS | 0.000000 |
| -3.0 | +3.0 | PASS | 0.000000 |
| +0.0 | -3.0 | PASS | 0.000000 |
| +0.0 | +0.0 | PASS | 0.000000 |
| +0.0 | +3.0 | PASS | 0.000000 |
| +3.0 | -3.0 | PASS | 0.000000 |
| +3.0 | +0.0 | PASS | 0.000000 |
| +3.0 | +3.0 | PASS | 0.000000 |

All nine CAD results: **PASS**.

## Limits and next gate

- This finite sampling is not a continuous-workspace proof.
- Actual actuator internal limit-switch trip points remain unverified.
- Guide overlap is not asserted unless the modeled assemblies explicitly contain and check that guide.
- This result grants no fabrication or purchase release.
- If a later physical guide or cable check fails, retain the physical Z=15 mm datum and reduce command maximum Z to 35 mm.

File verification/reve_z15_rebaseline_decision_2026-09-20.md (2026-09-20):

# Rev E Z+15 명령 기준점 재기준화 결정 — 2026-09-20

## 결정 상태

`POWERED_PROFILE_RADIAL_3RPS_REVE`의 명령 기준점을 아래와 같이 동결한다. 이 문서는 `design_basis/powered_reve_rebaseline_concept_2026-09-17.md` 및 `requirements/current_variant_priority_2026-09-17.md`의 운전범위 문구를 해석하는 기준 기록이다.

| 항목 | 동결된 값 또는 규칙 |
|---|---|
| 대상 액추에이터 | `LM4075OE-1075 / DC24V / 100 mm / 750 N / encoder 5 V / 6 ppr`, 3축 |
| 명령 원점 | pitch=0°, roll=0°에서 물리 Z=15 mm를 명령 Z=0으로 정의 |
| 명령 매핑 | 명령 Z=0~50 mm는 물리 Z=15~65 mm에 대응 |
| 각도 범위 | 명령 Z 전 범위에서 pitch/roll 동시 ±3° |
| 기본 CAD 외곽 | 700×700×315 mm; 케이블, 전장함, E-stop 및 기타 전기 돌출부 제외 |
| 명목 요구 핀 길이 범위 | 221.281~289.523 mm |
| 잠정 소프트웨어 창 | 218~292 mm |
| 기존 CAD/STEP 명목 범위 | 205~305 mm; 검증된 내장 리미트 스위치 작동점이 아님 |

물리 Z=15 mm는 액추에이터의 물리 하한이나 내장 리미트 위치가 아니다. 물리 Z=65 mm는 명령 Z=50 mm의 수평 기준 높이이며, 현 시점에서 중앙 가이드 겹침 또는 전체 CAD로 최종 확인되지 않았다.

## 운전 및 시운전 규칙

- 정상 운전은 내장 하한 또는 상한 리미트에 의도적으로 접촉하지 않는다.
- 일반 HOME과 자동운전은 저장된 유효 위치 상태, 저장된 물리 Z=15 mm 명령 기준점 오프셋, 그리고 전원 차단 중 또는 이후에 이동이 없었다는 무이동 조건을 검증한 경우에만 허용한다. 일반 HOME은 그 저장된 물리 Z=15 mm 기준점으로 복귀할 뿐, 내장 하한 또는 상한 리미트를 의도적으로 탐색하거나 접촉하지 않는다.
- 자동운전 전에 시운전에서 축별 실제 `L_low_switch` 및 `L_high_switch`를 기록한다. 기록값을 사용해 HOME 오프셋, 스트로크, 소프트웨어 창, 가이드/간섭 및 스토퍼 검사를 다시 수행한다.
- 저장된 위치 상태·기준점·무이동 조건 중 하나라도 없거나 무효이면 `HOME_START_UNVERIFIED`로 일반 HOME과 자동운전을 거부한다. 보유 블록으로 지지한 감독하 `COMMISSIONING_HOME` 또는 `HOME_START_UNVERIFIED` 복구에서만 내장 리미트 탐색·접촉과 재접근을 수행할 수 있다. 그 동작 뒤에는 자동 LEVEL을 시작하지 않으며, 일반 HOME 조건을 다시 충족·검증하기 전까지 LEVEL을 금지한다.
- 218~292 mm 창은 잠정 소프트웨어 보호창이며, 독립 기계식 스토퍼를 대체하지 않는다.
- 최종 중앙 가이드 겹침 또는 전체 CAD 스크리닝이 실패하면 물리 +15 mm 기준은 유지하고 명령 Z 상한만 35 mm로 제한한다. 이 경우 명령 Z=0~35 mm는 물리 Z=15~50 mm에 대응한다.

## 안전 편차와 릴리스 상태

현행 무독립-기계식-스토퍼 안전 편차는 변경하지 않는다. 전기 리미트와 독립 기계식 스토퍼 분리라는 프로젝트 기본 공학 규칙에 대한 충돌은 계속 구매·제작 릴리스를 막는다. 이 결정은 구매 릴리스, 제작 릴리스, 현장 안전, 인증, 사람 또는 적재물 사용을 승인하거나 주장하지 않는다.

## 아직 검증하지 않은 항목

- 각 축 실제 `L_low_switch` 및 `L_high_switch`
- 물리 Z=65 mm에서 중앙 가이드 겹침
- 실제 케이블 여유
- 모든 실물 시운전 결과

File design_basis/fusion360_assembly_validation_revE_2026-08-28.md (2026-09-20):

# Fusion 360 상세 조립 검증 Rev E

작성일: 2026-08-28

## 판정

상부 수평유지 모듈은 Rev E 디지털 조립 시험 기준으로 **조건부 통과**다. 3개 방사형 액추에이터, 하부/상부 4040 프레임, 2축 가이드, 직렬 카단, 상판과 모델링된 체결구는 지정 자세에서 조립 및 이동이 가능하다.

이 판정은 제작 승인이나 안전 인증이 아니다. 실제 A2 액추에이터 양단 인터페이스, LMF12UU/SK12 구멍, JFT-8R 스페이서, 카트측 리시버와 아직 선정되지 않은 M4 체결품은 입고 측정 또는 판매처 회신으로 닫아야 한다. 카트 결합부는 실제 카트 치수가 확정되지 않아 이번 통과 판정에서 제외했다.

## 시험 범위와 방법

- CadQuery B-rep 솔리드의 교차 부피를 계산했다. 허용 기준은 의도하지 않은 교차 부피 0.01 mm3 이하이다.
- Z 이동 0~100 mm를 10 mm 간격으로 검사하고, 중간 높이에서 pitch +3도, roll +3도, pitch/roll 동시 +3도를 추가해 총 14개 자세를 검사했다.
- 이동 가이드 대 고정 가이드/하부 프레임/상부 프레임, 액추에이터 포락체 대 중앙 가이드/카단을 검사했다.
- 12 mm 축, M8 카단 핀, LMF/SK M4 나사, 상판 나사와 압축 슬리브가 모델링된 구멍을 통과하는지 검사했다.
- 상/하 브리지 접촉, 상부 중앙 레일 분리, 카단 두 핀 분리, 기계식 Z 스토퍼 여유와 연결 전 전체 높이를 검사했다.

## 정량 결과

| 항목 | 결과 | 판정 |
|---|---:|---|
| 검사 자세 | 14 | 통과 |
| 가이드 이동부의 의도하지 않은 교차 | 0 | 통과 |
| 액추에이터와 중앙부 교차 | 0 | 통과 |
| 축/핀/나사/슬리브 구멍 간섭 | 0 | 통과 |
| 하부 카단 브리지-캐리지 거리 | 0.0 mm | 접촉 |
| 상부 카단 브리지-두 중앙 레일 거리 | 각각 0.0 mm | 접촉 |
| 상부 중앙 레일 사이 간격 | 60.0 mm | 교차 없음 |
| 카단 X/Y 핀 최소 솔리드 간격 | 4.0 mm | 교차 없음 |
| 접힘/상승 명령점의 Z 스토퍼 여유 | 각각 2.0 mm | 통과 |
| 연결 전 모듈 포락체 | 900 x 800 x 300 mm | 통과 |
| 분리된 카트 참조 그룹과 모듈의 수직 간격 | 56.0 mm | 비조립 참조 표시 |

기계적 위치 수치와 자동 판정은 `calculations/navimro_assembly_feasibility.py` 및 생성물 `NAVIMRO_revE_assembly_audit.json`으로 재현한다.

## Rev D에서 발견한 실제 조립 문제

1. 상부 중앙 420 mm 프로파일 두 개가 같은 높이에서 직교해 솔리드가 서로 관통했다.
2. 카단 X/Y M8 핀이 한 중심에서 서로 관통했고, 요크와 적층 블록에 실제 보어가 없었다.
3. SK12가 표준 설치 방향과 맞지 않았으며 LMF12UU/SK12 체결 구멍이 빠져 있었다.
4. 이동식 축 칼라가 고정 LMF12UU를 통과해야 하는 구조였다.
5. 가이드축이 하부 프레임 횡재를 관통했고, 아크릴 상판 나사도 무가공 판을 관통했다.
6. 50 mm 평철로 만들 수 없는 50 x 64 mm 단일 이동 스토퍼 판이 사용됐다.
7. 상판 5 mm 스페이서가 아크릴 솔리드 내부에 겹쳐 있었다.
8. CAD의 액추에이터 공급 스트로크가 사용자가 확인한 150 mm가 아니라 과거 100 mm 값으로 남아 있었다.

## Rev E 수정 내용

- 상부 중앙 레일을 평행한 420 mm 두 줄로 배치하고 60 mm 간격을 확보했다.
- 카단 축을 Z 방향으로 12 mm 분리한 직렬 구조로 만들고, 4장 적층 50 x 50 x 24 mm 블록과 실제 보어를 적용했다.
- 가이드는 고정 LMF12UU 4개, 이동 SK12 2개, 12 x 230 mm 축 2개와 단일 240 mm 캐리지로 정리했다.
- 가이드 리저를 축 바깥 40 mm로 옮기고 50 x 76 mm LMF 전사 드릴 탭으로 연결했다.
- 스토퍼는 고정 50 x 18 조각 4개와 이동측 50 x 32/40 조각 각 2개로 만들었다. SK 볼트와 리저를 피하면서 명령 끝점 밖 2 mm에서 접촉한다.
- 하부 프레임에는 축용 13.2 mm 통과 구멍을, 상판에는 ID8.6/OD18/L15 압축 슬리브용 18.2 mm 구멍 16개를 적용했다.
- 상판 와셔를 아크릴 상면으로 옮기고 전체 포락체를 300 mm로 맞췄다.
- 공급 액추에이터 스트로크 입력을 150 mm로 바로잡았다.

LMF12UU와 SK12는 웹에 보이는 보편 치수 포락체로 모델링했지만 나비엠알오 납품품의 최종 구멍은 전사 드릴한다. 참고한 제조사 계열 자료는 [THK SK shaft support](https://www.thk.com/us/en/products/other_linear_motion_guides/linear_bushing/lm_shaft_end_support/sk/)와 [SBC SK support table](https://www.sbclinear.co.jp/products/bush/sk.html)이다.

## 권장 조립 순서

1. 하부 4040 프레임을 직각 지그에서 조립하고 두 가이드축 통과 구멍을 확인한다.
2. P06 리저, P17 발, P09 탭을 가접한다. 실제 LMF12UU를 탭에 대고 구멍을 전사한 뒤 두 축을 정렬 지그로 사용해 최종 용접한다.
3. 단일 240 mm 캐리지에 SK12용 M4 T너트를 먼저 넣고, 캐리지를 중간 높이에 둔 상태에서 SK12 두 개를 옆면 체결한다.
4. 230 mm 축 두 개를 LMF12UU와 SK12에 통과시킨다. 손으로 전 스트로크를 왕복해 걸림이 없을 때만 SK12 클램프와 리저 체결을 마감한다.
5. 이동 스토퍼 내/외 조각은 축 구멍을 맞춘 상태에서 캐리지에 체결한다. 고정 스토퍼는 접힘/상승 명령점에서 2 mm 여유를 게이지로 설정한 뒤 용접한다.
6. 캐리지 위에 하부 카단 브리지, 하부 요크, 4층 적층 블록, 상부 요크와 상부 브리지를 순서대로 조립한다. M8 두 핀은 서로 다른 높이의 보어에 들어간다.
7. 상부 4040 프레임을 카단 브리지에 체결하고 3개 상/하 액추에이터 요크를 핀 정렬 지그로 용접한다.
8. JFT-8R 및 실제 A2 어댑터 치수를 측정해 스페이서를 가공한 뒤, 3개 액추에이터를 하부부터 상부 순으로 핀 체결한다.
9. 무부하 수동 이동과 저전압 단축 시험을 마친 뒤 상판 압축 슬리브와 아크릴을 마지막에 체결한다. 카단과 SK12 정비 시에는 상판을 제거하고 캐리지를 중간 높이에 둔다.

## 아직 닫히지 않은 항목

- A2 실제 양단 M8 암/수, 물림 길이, pin-center 최소/최대 길이, Hall 배선과 실제 STEP.
- LMF12UU/SK12 납품품 구멍·카운터보어와 정확한 M4 볼트/T너트/너트 나비엠알오 SKU.
- JFT-8R 실제 볼 폭에 맞춘 스페이서와 M8 비나사 베어링 구간.
- 상판 압축 슬리브의 구매품 또는 절단용 튜브 SKU.
- 카트측 리시버 레일, 로케이터, 래치의 최종 위치. 실제 카트 치수 없이 현재 카트 결합 형상을 제작하면 안 된다.
- 동적 하중, 용접 변형, 프로파일 슬롯 미끄럼, 피로, 제어 오차와 전기적 회생/과전류는 이번 CAD 간섭 시험의 범위가 아니다.

## 발주 영향

Rev E는 240 mm 캐리지를 2개에서 1개로, SK12 2개입 팩을 2팩에서 1팩으로 줄이고 축 칼라 4개를 삭제했다. 현재 가격이 있는 나비엠알오 품목 소계는 VAT 포함 2,687,993원이다. 다만 M4 체결품, 상판 슬리브와 TVS가 아직 정확한 주문행으로 추가되지 않았으므로 이 문서만으로 일괄 발주하면 안 된다.

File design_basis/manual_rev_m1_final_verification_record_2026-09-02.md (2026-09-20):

# Manual 3-RPS Rev M1 final verification record

## 1. Frozen design basis

- Manual 3-RPS upper leveling/lifting module; no powered actuator or electrical control in the active design.
- Lower and upper profile frames: `700 x 700` envelope.
- Collapsed height: `300 mm`; common Z adjustment target `50 mm`; pitch and roll target `+/-3 deg`.
- Lower/upper support radii: `75 / 250 mm`; support azimuths `90/210/330 deg`.
- Permitted platform motions: Z, pitch, roll. The three radial RPS legs constrain X, Y, and yaw.
- Design leg load `600 N`; total test article mass basis remains 20 kg (10 kg cart estimate plus 10 kg payload), with no people carrying claim.

## 2. Product-image and catalog evidence

The dimensions were not inferred from generic thumbnails. The saved official evidence is under `web_research/evidence/2026-09-01/manual_rev_m1/`.

- THK PHS10: bore10 H7, OD26, ring width14, overall56, centre-to-thread-end43, M10 x1.5, thread depth21, static radial capacity13.2 kN, permissible tilt at least8 deg.
- IMAO BJ775-08040-SUS: diameter8, maximum envelope9.4, grip40 +0.5/0, end allowance8 +/-1, mass42 g; recommended mounting hole `diameter8 +0.1/0`.
- igus JFM-2528-21: ID25, OD28, flange OD35, L21, flange t1.5; housing `28.000..28.021`; shaft `24.948..25.000`.
- NAVIMRO profile/bracket images: DNF4040 slot8.3 +/-0.3; DNF3030 slot6.3 +0.2/0; 4035 envelope40 x40 x35; DCB3025 envelope30 x30 x25.

## 3. Detailed Fusion model

- Native file: `outputs/manual_3rps_rev_m1_fusion_native/Manual_3RPS_RevM1_NATIVE.f3d`.
- Neutral STEP: `outputs/manual_3rps_rev_m1_fusion_native/Manual_3RPS_RevM1_NEUTRAL.step`.
- Native leaf components: 129; neutral STEP solids: 253.
- Functional groups exported separately: lower frame, lower brackets, lower adapters, lower joints, manual struts, upper frame, upper brackets, upper joints, fasteners.
- Every bolt, slot-nut proxy, pivot set, shim, coarse pin, guide, bushing, plug, jam nut, and frame item is positioned in the native assembly.

## 4. Engineering checks

- 27-point workspace sweep: Z `0/25/50`, pitch `-3/0/+3`, roll `-3/0/+3` degrees.
- Required pin-centre range: `219.1426..279.6423`; available manual range `213..303`; margins `6.1426 / 23.3577`.
- Maximum 3-RPS constraint residual: `6.54e-13 mm`.
- Maximum PHS articulation demand: `4.096 deg`, below the catalog minimum permissible `8 deg`.
- PHS10 static-capacity factor at 600 N: `22.0`; conservative M10 engagement factor `13.16`; outer-tube Euler factor `119`; coarse-hole bearing stress `18.75 MPa`.

## 5. Interference and section troubleshooting

Initial Fusion interference run found 20 positive-volume contacts. Review identified four causes:

1. M5 plug retainer intersected the M10 fine-adjustment stud.
2. Upper clevis gap16 was narrower than the modeled PHS10 holder envelope17.
3. A2/A3 upper mounting bolts intersected rotated clevis ears.
4. Slot-nut proxies penetrated profile walls by 0.1 mm.

Corrections moved the retainer, changed the upper gap to20 with two 3 mm shims, widened the upper base to100 with 84 mm mounting pitch, and corrected slot-nut Z. The next run had six contacts because the M5 retainer still touched the JFM flange. The retainer was changed to M4 with 32 mm modeled grip and moved to a 22.5 mm offset. Fusion then returned zero contacts.

During final product-dimension reconciliation, the coarse holes were corrected from `diameter8.2` to the IMAO recommendation `diameter8 +0.1/0`. This affects 21 cross holes across the three struts. All checks were rerun after this change.

## 6. Corrected verification round 1

- Fusion `Design.analyzeInterference`: three passes, 129 leaf occurrences each, zero contacts in every pass, repeatable.
- Fusion section analyses: three A1 sections at X offsets `0/+3/-3`; tube nesting, JFM/guide/plug/stud stack, both clevises, shims, and pivot paths visually inspected.
- Independent CadQuery/OpenCascade STEP audit: envelope `700 x700 x300`; 36 cross-group reports zero; nine within-group reports zero; cross/internal collision counts `0/0`.
- BOM-CAD audit: three passes; 28 BOM rows; all 129 native component names covered; zero uncovered; all quantities matched; no active electrical item; projected budget below 4,000,000 KRW.

## 7. Corrected verification round 2

The unchanged corrected source was regenerated in Fusion and the complete sequence above was repeated.

- Fusion interference passes: `0 / 0 / 0`.
- Fusion section passes: three regenerated images.
- Independent STEP audit: 253 solids, `700 x700 x300`, cross/internal collisions `0 / 0`.
- BOM-CAD passes: three, repeatable, all pass; 129/129 components covered.
- Round 2 results match round 1.

## 8. BOM and budget

- Canonical data: `procurement/manual_rev_m1_bom_data_2026-09-02.json`.
- BOM rows: 28.
- Known VAT-included subtotal: 320,845 KRW.
- Budgetary total including quote allowances: 2,257,845 KRW.
- Remaining against 4,000,000 KRW cap: 1,742,155 KRW.
- Quote/option-selection rows: 13.
- Active BOM excludes actuators, controllers, batteries, sensors, diodes, fuses, and all other powered-control parts. The prior powered architecture remains archived in `design_basis/archived_powered_control_architecture_2026-09-01.md`.

## 9. Verification-tool issue and correction

The first BOM electrical-item scan falsely detected `IMU` inside the word `aluminum`. The scan was corrected from substring matching to alphanumeric word-boundary matching, then all three BOM-CAD passes were rerun successfully. This did not change the BOM or CAD.

## 10. Order-release decision

The design is ready for supplier quotation and one-set trial manufacture, but not for unconditional batch ordering. Release remains on hold until:

- exact BJ775-08040-SUS delivered quote and code confirmation;
- tube stock inspection confirms JFM shaft/housing tolerances are achievable;
- supplier drawings for both shoulder-pin sets and DIN439 M10 thin nuts are accepted;
- one A1 custom-part set is dry-built and measured before the other two sets are finalized.

This record does not claim certification, field safety, or suitability for carrying people.

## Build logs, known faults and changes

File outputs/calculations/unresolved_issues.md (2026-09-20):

# 미해결 이슈 및 승인 전 질문

> 본 목록은 문제를 숨기지 않고 Phase 2 입력으로 관리하기 위한 것이다.

## P0 - 개념 승인과 동시에 결정 필요

1. **하중 정의 충돌**  
   최신 프롬프트의 페이로드 5/10/20 kg를 기준으로 할지, 참고 슬라이드의 100 kg를 목표로 복원할지 확인이 필요하다. 100 kg가 페이로드인지 카트·장치 포함 총질량인지도 구분해야 한다.

2. **실제 카트 하부 인터페이스 치수**  
   `cart_interface_length_mm`, `cart_interface_width_mm`, 프레임 부재 폭/높이, 체결 가능한 위치, 바닥에서 하부 프레임까지의 높이, 허용 가공 여부가 필요하다. 이미지 측정값은 사용하지 않았다.

3. **보정각 승인**  
   1차 PoC 권장값은 Pitch/Roll 각각 ±3°이다. ±5°를 필수로 하면 액추에이터 유효 스트로크가 약 215 mm로 커지고 수축 높이가 증가한다. ±8°는 현 개념에서 권장하지 않는다.

4. **수축 높이 허용치**  
   250 mm가 절대 상한인지 목표값인지 확인이 필요하다. 현재 추천안은 270 ±15 mm로 추정한다.

5. **하부 이동체 장착조건**  
   사용 가능한 장착면 크기, 볼트 패턴, 허용 수직하중/모멘트, 지지다각형, 전도 기준이 없다. 700×600 mm는 임시 인터페이스 파라미터다.

## P1 - Phase 2 모델링 전에 확보

6. **카트와 자재의 무게중심**  
   카트 자체 질량, 빈 카트/적재 카트의 X/Y 편심, 결합면 위 무게중심 높이, 최악 적재 형상이 필요하다.

7. **액추에이터 설치 가능 공간**  
   조인트 중심 132-288 mm 범위, ≥175 mm 유효 스트로크, ≥1.5 kN 동적 추력, ≥2.0 kN 정적 유지 조건을 동시에 만족하는 제품 또는 스크루잭 형상이 필요하다.

8. **속도와 듀티사이클**  
   100 mm 리프트 시간, 수평 보정 속도, 시간당 사이클, 연속 동작 시간, 소음 요구가 없다.

9. **전원과 제어 플랫폼**  
   공급전압, 최대전류, 컨트롤러 종류, 통신 방식, 비상정지 회로 범위가 없다.

10. **환경조건**  
    실내/실외, 먼지·수분, 온도, 바닥 경사, 진동·충격, 부식 환경이 없다.

11. **카트 결합 조작 방향**  
    카트를 수직으로 내려놓는지, 측면으로 밀어 넣는지, 한쪽 접근만 가능한지, 작업자 손이 닿는 래치 위치가 필요하다.

12. **카트측 브래킷 허용 여부**  
    카트에 교체식 어댑터 레일/브래킷을 볼트 체결할 수 있는지, 무가공 클램프만 허용되는지 확인이 필요하다.

## P2 - 상세설계와 시험계획에서 결정

13. 중앙 키드 슬라이드의 형식: 사각 키, 스플라인, 이중 LM 가이드 또는 토크 튜브 비교
14. 카단 조인트의 허용각, 토크, 백래시, 베어링 수명
15. 액추에이터의 자가잠김/브레이크 방식과 수동 비상 하강 절차
16. 기계식 상·하한 및 각도 스토퍼의 위치, 교체식 범퍼 재질
17. 손 끼임 가드와 벨로즈의 형상, 유지보수 접근성
18. 라운드/다이아몬드 로케이터 공차, 테이퍼 진입각, 래치 인장력
19. 체결 센서 수량과 이중화 수준
20. IMU 정밀도, AUTO LEVEL deadband, 목표 수평오차
21. 정적 하중, 편심 하중, 전원 차단, 센서 고장, 한 축 정지 시험 절차
22. 4백만원 예산 내 견적 적합성 및 단계 구매 여부

## 승인 제안

Phase 2로 진행하려면 최소한 다음 네 항목을 승인 또는 임시값으로 지정해야 한다.

- 대안 A 채택 여부
- Pitch/Roll 각각 ±3° 채택 여부
- 270 ±15 mm 예상 수축 높이 허용 여부
- 5/10/20 kg 페이로드 기준 유지 여부

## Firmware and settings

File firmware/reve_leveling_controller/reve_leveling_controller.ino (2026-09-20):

#include <EEPROM.h>
#include <Wire.h>

// Rev E stationary bench PoC controller. This is not safety-rated firmware.

enum ControllerState : uint8_t { INIT, HOMING, IDLE, MOVING, LEVELING, FAULT };
enum FaultCode : uint8_t {
  FAULT_NONE,
  FAULT_NOT_HOMED,
  FAULT_CALIBRATION_MISSING,
  FAULT_ENCODER_NO_PULSE,
  FAULT_ENCODER_DIRECTION,
  FAULT_IMU_STALE,
  FAULT_TILT_LIMIT,
  FAULT_MOTION_TIMEOUT,
  FAULT_TRAVEL_LIMIT,
  FAULT_BAD_COMMAND
};

constexpr uint8_t AXES = 3;
constexpr uint8_t ENC_A[AXES] = {2, 3, 18};
constexpr uint8_t ENC_B[AXES] = {22, 23, 24};
constexpr uint8_t MOTOR_PWM[AXES] = {5, 6, 7};
constexpr uint8_t MOTOR_DIR[AXES] = {30, 31, 32};
constexpr uint8_t UNUSED_PWM = 8;
constexpr uint8_t UNUSED_DIR = 33;
constexpr uint8_t MPU_ADDR = 0x68;

constexpr uint32_t TELEMETRY_PERIOD_MS = 100;
constexpr uint32_t IMU_STALE_MS = 200;
constexpr uint32_t NO_PULSE_MS = 500;
constexpr uint32_t REVERSE_PAUSE_MS = 100;
constexpr uint32_t MOTION_TIMEOUT_MS = 30000;
constexpr uint32_t HOME_AXIS_TIMEOUT_MS = 15000;
constexpr uint32_t LEVEL_HOLD_MS = 10000;
constexpr float LEVEL_TOLERANCE_DEG = 0.5f;
constexpr float TILT_FAULT_DEG = 5.0f;
constexpr float LEVEL_STEP_MM = 0.25f;
constexpr float MAX_POSITION_MM = 100.0f;
constexpr uint8_t HOME_PWM = 70;
constexpr uint8_t MOVE_PWM = 105;
constexpr uint8_t PWM_RAMP_STEP = 5;
constexpr uint32_t PWM_RAMP_PERIOD_MS = 20;

struct Calibration {
  uint32_t magic;
  float countsPerMm[AXES];
  float dLengthDpitch[AXES];
  float dLengthDroll[AXES];
  float imuPitchZero;
  float imuRollZero;
};

constexpr uint32_t CAL_MAGIC = 0x52455645UL;
Calibration cal = {
  CAL_MAGIC,
  {0.0f, 0.0f, 0.0f},
  {-0.194842f, 3.006702f, -2.811860f},
  {3.359349f, -1.510936f, -1.848413f},
  0.0f,
  0.0f
};

volatile long encoderCount[AXES] = {0, 0, 0};
volatile uint32_t encoderPulseMs[AXES] = {0, 0, 0};

ControllerState state = INIT;
FaultCode faultCode = FAULT_NONE;
bool homed = false;
float pitchDeg = 0.0f;
float rollDeg = 0.0f;
uint32_t lastImuMs = 0;
uint32_t lastTelemetryMs = 0;
uint32_t levelWithinToleranceSinceMs = 0;

struct AxisMotion {
  bool active;
  uint8_t axis;
  int8_t direction;
  long startCount;
  long targetCount;
  uint8_t pwm;
  uint32_t startedMs;
  uint32_t lastRampMs;
  uint32_t reverseReadyMs;
};

AxisMotion motion = {false, 0, 0, 0, 0, 0, 0, 0, 0};
uint8_t appliedPwm[AXES] = {0, 0, 0};
bool liftActive = false;
float liftTargetMm = 0.0f;
uint8_t homeAxis = 0;
uint32_t homeAxisStartedMs = 0;
long homeLastCount = 0;
uint32_t homeLastChangeMs = 0;

char commandBuffer[128];
uint8_t commandLength = 0;

const char *stateName(ControllerState value) {
  switch (value) {
    case INIT: return "INIT";
    case HOMING: return "HOME";
    case IDLE: return "IDLE";
    case MOVING: return "MOVING";
    case LEVELING: return "LEVELING";
    case FAULT: return "FAULT";
  }
  return "UNKNOWN";
}

void encoderEdge(uint8_t axis) {
  bool a = digitalRead(ENC_A[axis]);
  bool b = digitalRead(ENC_B[axis]);
  encoderCount[axis] += (a == b) ? 1 : -1;
  encoderPulseMs[axis] = millis();
}

void encoder0() { encoderEdge(0); }
void encoder1() { encoderEdge(1); }
void encoder2() { encoderEdge(2); }

long atomicCount(uint8_t axis) {
  noInterrupts();
  long value = encoderCount[axis];
  interrupts();
  return value;
}

void setAtomicCount(uint8_t axis, long value) {
  noInterrupts();
  encoderCount[axis] = value;
  encoderPulseMs[axis] = millis();
  interrupts();
}

bool calibrationValid() {
  for (uint8_t axis = 0; axis < AXES; ++axis) {
    if (!isfinite(cal.countsPerMm[axis]) || cal.countsPerMm[axis] <= 0.0f) return false;
    if (!isfinite(cal.dLengthDpitch[axis]) || !isfinite(cal.dLengthDroll[axis])) return false;
  }
  return cal.magic == CAL_MAGIC;
}

void allStop() {
  for (uint8_t axis = 0; axis < AXES; ++axis) {
    analogWrite(MOTOR_PWM[axis], 0);
    appliedPwm[axis] = 0;
  }
  analogWrite(UNUSED_PWM, 0);
  digitalWrite(UNUSED_DIR, LOW);
  motion.active = false;
}

void enterFault(FaultCode code) {
  allStop();
  faultCode = code;
  state = FAULT;
}

void clearFault() {
  allStop();
  faultCode = FAULT_NONE;
  state = homed ? IDLE : INIT;
}

bool readMpu6050() {
  Wire.beginTransmission(MPU_ADDR);
  Wire.write(0x3B);
  if (Wire.endTransmission(false) != 0) return false;
  if (Wire.requestFrom(MPU_ADDR, static_cast<uint8_t>(14), static_cast<uint8_t>(true)) != 14) return false;

  int16_t ax = (Wire.read() << 8) | Wire.read();
  int16_t ay = (Wire.read() << 8) | Wire.read();
  int16_t az = (Wire.read() << 8) | Wire.read();
  Wire.read(); Wire.read();
  Wire.read(); Wire.read();
  Wire.read(); Wire.read();
  Wire.read(); Wire.read();

  float rawRoll = atan2f(static_cast<float>(ay), static_cast<float>(az)) * 57.2957795f;
  float rawPitch = atan2f(-static_cast<float>(ax), sqrtf(static_cast<float>(ay) * ay + static_cast<float>(az) * az)) * 57.2957795f;
  rollDeg = rawRoll - cal.imuRollZero;
  pitchDeg = rawPitch - cal.imuPitchZero;
  lastImuMs = millis();
  return true;
}

void startAxisCounts(uint8_t axis, long deltaCounts, uint8_t requestedPwm) {
  if (axis >= AXES || deltaCounts == 0) return;
  long start = atomicCount(axis);
  int8_t direction = deltaCounts > 0 ? 1 : -1;
  allStop();
  digitalWrite(MOTOR_DIR[axis], direction > 0 ? HIGH : LOW);
  motion = {true, axis, direction, start, start + deltaCounts, 0, millis(), millis(), millis() + REVERSE_PAUSE_MS};
  motion.pwm = min(requestedPwm, static_cast<uint8_t>(200));
}

bool startAxisMm(uint8_t axis, float deltaMm, uint8_t requestedPwm = MOVE_PWM) {
  if (!calibrationValid()) {
    enterFault(FAULT_CALIBRATION_MISSING);
    return false;
  }
  long deltaCounts = lroundf(deltaMm * cal.countsPerMm[axis]);
  if (deltaCounts == 0) deltaCounts = deltaMm > 0.0f ? 1 : -1;
  float targetMm = static_cast<float>(atomicCount(axis) + deltaCounts) / cal.countsPerMm[axis];
  if (targetMm < 0.0f || targetMm > MAX_POSITION_MM) {
    enterFault(FAULT_TRAVEL_LIMIT);
    return false;
  }
  startAxisCounts(axis, deltaCounts, requestedPwm);
  return true;
}

void serviceMotion() {
  if (!motion.active) return;
  uint32_t now = millis();
  long current = atomicCount(motion.axis);
  long traveled = current - motion.startCount;

  if (now - motion.startedMs > MOTION_TIMEOUT_MS) {
    enterFault(FAULT_MOTION_TIMEOUT);
    return;
  }
  if (now > motion.startedMs + 250 && traveled != 0 && ((traveled > 0) != (motion.direction > 0))) {
    enterFault(FAULT_ENCODER_DIRECTION);
    return;
  }
  if (now > motion.startedMs + NO_PULSE_MS && now - encoderPulseMs[motion.axis] > NO_PULSE_MS) {
    enterFault(FAULT_ENCODER_NO_PULSE);
    return;
  }
  if ((motion.direction > 0 && current >= motion.targetCount) ||
      (motion.direction < 0 && current <= motion.targetCount)) {
    analogWrite(MOTOR_PWM[motion.axis], 0);
    appliedPwm[motion.axis] = 0;
    motion.active = false;
    if (state == MOVING && !liftActive) state = IDLE;
    return;
  }
  if (now >= motion.reverseReadyMs && now - motion.lastRampMs >= PWM_RAMP_PERIOD_MS) {
    uint8_t &applied = appliedPwm[motion.axis];
    if (applied < motion.pwm) applied = min(static_cast<int>(motion.pwm), static_cast<int>(applied + PWM_RAMP_STEP));
    analogWrite(MOTOR_PWM[motion.axis], applied);
    motion.lastRampMs = now;
  }
}

void beginHomeAxis() {
  if (homeAxis >= AXES) {
    allStop();
    homed = true;
    state = IDLE;
    return;
  }
  allStop();
  digitalWrite(MOTOR_DIR[homeAxis], LOW);
  homeAxisStartedMs = millis();
  homeLastChangeMs = homeAxisStartedMs;
  homeLastCount = atomicCount(homeAxis);
  analogWrite(MOTOR_PWM[homeAxis], HOME_PWM);
}

void serviceHoming() {
  uint32_t now = millis();
  long current = atomicCount(homeAxis);
  if (current != homeLastCount) {
    homeLastCount = current;
    homeLastChangeMs = now;
  }
  if (now - homeAxisStartedMs > HOME_AXIS_TIMEOUT_MS) {
    enterFault(FAULT_MOTION_TIMEOUT);
    return;
  }
  // The actuator's internal retract limit removes motor power. No pulse is used
  // only during supervised HOME as the endpoint indication.
  if (now - homeLastChangeMs > 700) {
    analogWrite(MOTOR_PWM[homeAxis], 0);
    setAtomicCount(homeAxis, 0);
    ++homeAxis;
    beginHomeAxis();
  }
}

void serviceLeveling() {
  if (motion.active) return;
  float maxError = max(fabsf(pitchDeg), fabsf(rollDeg));
  if (maxError <= LEVEL_TOLERANCE_DEG) {
    if (levelWithinToleranceSinceMs == 0) levelWithinToleranceSinceMs = millis();
    if (millis() - levelWithinToleranceSinceMs >= LEVEL_HOLD_MS) state = IDLE;
    return;
  }
  levelWithinToleranceSinceMs = 0;

  float correction[AXES];
  float mean = 0.0f;
  for (uint8_t axis = 0; axis < AXES; ++axis) {
    correction[axis] = -(cal.dLengthDpitch[axis] * pitchDeg + cal.dLengthDroll[axis] * rollDeg);
    mean += correction[axis];
  }
  mean /= AXES;
  uint8_t selected = 0;
  float selectedCorrection = 0.0f;
  for (uint8_t axis = 0; axis < AXES; ++axis) {
    correction[axis] -= mean;
    if (fabsf(correction[axis]) > fabsf(selectedCorrection)) {
      selected = axis;
      selectedCorrection = correction[axis];
    }
  }
  float step = selectedCorrection >= 0.0f ? LEVEL_STEP_MM : -LEVEL_STEP_MM;
  startAxisMm(selected, step, MOVE_PWM);
}

void serviceLift() {
  if (!liftActive || motion.active || state == FAULT) return;
  uint8_t selected = AXES;
  float largest = 0.0f;
  for (uint8_t axis = 0; axis < AXES; ++axis) {
    float delta = liftTargetMm - static_cast<float>(atomicCount(axis)) / cal.countsPerMm[axis];
    if (fabsf(delta) > fabsf(largest)) {
      largest = delta;
      selected = axis;
    }
  }
  if (selected == AXES || fabsf(largest) <= 0.05f) {
    liftActive = false;
    state = IDLE;
    return;
  }
  startAxisMm(selected, largest);
}

void printTelemetry() {
  uint32_t now = millis();
  if (now - lastTelemetryMs < TELEMETRY_PERIOD_MS) return;
  lastTelemetryMs = now;
  Serial.print(now); Serial.print(',');
  Serial.print(stateName(state)); Serial.print(',');
  Serial.print(pitchDeg, 3); Serial.print(',');
  Serial.print(rollDeg, 3);
  for (uint8_t axis = 0; axis < AXES; ++axis) {
    Serial.print(','); Serial.print(atomicCount(axis));
  }
  for (uint8_t axis = 0; axis < AXES; ++axis) {
    Serial.print(','); Serial.print(axis == motion.axis && motion.active ? motion.pwm : 0);
    Serial.print(','); Serial.print(axis == motion.axis && motion.active ? motion.direction : 0);
  }
  Serial.print(','); Serial.println(static_cast<int>(faultCode));
}

void parseCommand(char *line) {
  char *command = strtok(line, " ,\t");
  if (!command) return;
  for (char *p = command; *p; ++p) *p = toupper(*p);

  if (!strcmp(command, "STATUS")) {
    printTelemetry();
  } else if (!strcmp(command, "STOP")) {
    liftActive = false;
    allStop();
    clearFault();
  } else if (!strcmp(command, "HOME")) {
    liftActive = false;
    clearFault();
    homed = false;
    homeAxis = 0;
    state = HOMING;
    beginHomeAxis();
  } else if (!strcmp(command, "ZERO_IMU")) {
    cal.imuPitchZero += pitchDeg;
    cal.imuRollZero += rollDeg;
    pitchDeg = 0.0f;
    rollDeg = 0.0f;
  } else if (!strcmp(command, "SAVE_CAL")) {
    float values[9];
    for (uint8_t i = 0; i < 9; ++i) {
      char *token = strtok(nullptr, " ,\t");
      if (!token) { enterFault(FAULT_BAD_COMMAND); return; }
      values[i] = atof(token);
    }
    for (uint8_t i = 0; i < AXES; ++i) cal.countsPerMm[i] = values[i];
    for (uint8_t i = 0; i < AXES; ++i) cal.dLengthDpitch[i] = values[3 + i];
    for (uint8_t i = 0; i < AXES; ++i) cal.dLengthDroll[i] = values[6 + i];
    cal.magic = CAL_MAGIC;
    if (!calibrationValid()) { enterFault(FAULT_BAD_COMMAND); return; }
    EEPROM.put(0, cal);
    clearFault();
  } else if (!strcmp(command, "JOG")) {
    char *axisToken = strtok(nullptr, " ,\t");
    char *distanceToken = strtok(nullptr, " ,\t");
    if (!homed) { enterFault(FAULT_NOT_HOMED); return; }
    if (!axisToken || !distanceToken) { enterFault(FAULT_BAD_COMMAND); return; }
    int axis = atoi(axisToken) - 1;
    float distance = atof(distanceToken);
    if (axis < 0 || axis >= AXES || distance == 0.0f) { enterFault(FAULT_BAD_COMMAND); return; }
    liftActive = false;
    state = MOVING;
    startAxisMm(axis, distance);
  } else if (!strcmp(command, "LIFT")) {
    char *heightToken = strtok(nullptr, " ,\t");
    if (!homed) { enterFault(FAULT_NOT_HOMED); return; }
    if (!heightToken) { enterFault(FAULT_BAD_COMMAND); return; }
    float height = atof(heightToken);
    if (height < 0.0f || height > 50.0f || !calibrationValid()) { enterFault(FAULT_BAD_COMMAND); return; }
    liftTargetMm = height;
    liftActive = true;
    state = MOVING;
    serviceLift();
  } else if (!strcmp(command, "LEVEL")) {
    if (!homed) { enterFault(FAULT_NOT_HOMED); return; }
    if (!calibrationValid()) { enterFault(FAULT_CALIBRATION_MISSING); return; }
    liftActive = false;
    levelWithinToleranceSinceMs = 0;
    state = LEVELING;
  } else {
    enterFault(FAULT_BAD_COMMAND);
  }
}

void serviceSerial() {
  while (Serial.available()) {
    char value = Serial.read();
    if (value == '\n' || value == '\r') {
      if (commandLength) {
        commandBuffer[commandLength] = '\0';
        parseCommand(commandBuffer);
        commandLength = 0;
      }
    } else if (commandLength < sizeof(commandBuffer) - 1) {
      commandBuffer[commandLength++] = value;
    }
  }
}

void setup() {
  Serial.begin(115200);
  Wire.begin();
  Wire.beginTransmission(MPU_ADDR);
  Wire.write(0x6B);
  Wire.write(0x00);
  Wire.endTransmission(true);

  for (uint8_t axis = 0; axis < AXES; ++axis) {
    pinMode(ENC_A[axis], INPUT_PULLUP);
    pinMode(ENC_B[axis], INPUT_PULLUP);
    pinMode(MOTOR_PWM[axis], OUTPUT);
    pinMode(MOTOR_DIR[axis], OUTPUT);
    analogWrite(MOTOR_PWM[axis], 0);
  }
  pinMode(UNUSED_PWM, OUTPUT);
  pinMode(UNUSED_DIR, OUTPUT);
  analogWrite(UNUSED_PWM, 0);
  digitalWrite(UNUSED_DIR, LOW);
  attachInterrupt(digitalPinToInterrupt(ENC_A[0]), encoder0, CHANGE);
  attachInterrupt(digitalPinToInterrupt(ENC_A[1]), encoder1, CHANGE);
  attachInterrupt(digitalPinToInterrupt(ENC_A[2]), encoder2, CHANGE);

  Calibration stored;
  EEPROM.get(0, stored);
  if (stored.magic == CAL_MAGIC) cal = stored;
  state = INIT;
  Serial.println("ms,state,pitch_deg,roll_deg,enc1,enc2,enc3,pwm1,dir1,pwm2,dir2,pwm3,dir3,fault");
}

void loop() {
  serviceSerial();
  readMpu6050();

  if (state != INIT && state != FAULT && millis() - lastImuMs > IMU_STALE_MS) enterFault(FAULT_IMU_STALE);
  if (state != INIT && state != HOMING && state != FAULT &&
      (fabsf(pitchDeg) > TILT_FAULT_DEG || fabsf(rollDeg) > TILT_FAULT_DEG)) enterFault(FAULT_TILT_LIMIT);

  if (state == HOMING) serviceHoming();
  if (state == MOVING || state == LEVELING) serviceMotion();
  if (state == MOVING) serviceLift();
  if (state == LEVELING && !motion.active) serviceLeveling();
  printTelemetry();
}

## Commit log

2026-09-20 chore: establish project baseline
    [2026 BIZ-Lab 창업클럽 시제품 재료비관리 현황_SAFELOCK.xlsx, 2026 BIZ-Lab 창업클럽 시제품 재료비관리 현황_견적반영.xlsx, 2026 BIZ-Lab 창업클럽 시제품 재료비관리 현황_공구제외.xlsx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]
2026-09-20 docs: gate DMC encoder multidrop compatibility
2026-09-20 docs: revise HMI-less preliminary BOM
    [reve_portenta_order_bom_2026-09-18.csv, reve_portenta_order_bom_2026-09-18.xlsx]
